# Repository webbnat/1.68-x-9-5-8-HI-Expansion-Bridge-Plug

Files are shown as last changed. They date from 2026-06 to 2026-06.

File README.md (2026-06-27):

# SHEX-BP-UHEX-54 — 1.68 × 9-5/8 High-Expansion Bridge Plug

Parametric engineering package for a retrievable, ultra-high-expansion downhole
bridge plug (1.68 in run-in OD, sets in 9-5/8 in casing) plus its setting
adapter kit and stage-1/2 internal actuators. Everything here is generated from
parametric CAD scripts: B-rep solids and STEP via `gmsh` (OpenCASCADE), 2D
manufacturing drawings via `ezdxf`, and figures/previews via `matplotlib`.

## Repository layout

```
cad/                     parametric solid models (release_solids, actuator_solids, ...)
generate_*.py            generators: full tool, actuators, setting kit
build_revisions.py       assembles the per-revision archive (Rev A / Rev B)
export/
  release/               released STEP parts + assemblies, drawings (dxf/pdf), manuals, figures
  full_tool/             complete tool: STEP + STL + previews (run-in & set)
  REVISIONS/             clean per-revision snapshots (see below)
  analysis/              engineering analysis scripts + memos (incl. DCN-12 trigger)
  drawings/              drawing generators + part specs
  _stl_archive/          large STL meshes as a multi-volume RAR (see its README)
```

## Revisions

| Revision | Folder | Complete tool (run-in / set) | Notes |
|---|---|---|---|
| **Rev B — current** | `export/REVISIONS/Rev-B_DCN-12_CURRENT/` | 47 / 48 bodies | adds the **SHEX-017** sequence/initiation sub (DCN-12 first-stroke trigger + EQ interlock) |
| Rev A — previous | `export/REVISIONS/Rev-A_DCN-01-11_PREVIOUS/` | 44 / 45 bodies | plug + setting kit + stage-1/2 bladder actuators |

Each revision folder is self-contained: engineering, design, part-specs,
drawings (dxf+pdf), STEP (parts/assemblies/full-tool), STL, and previews. See
`export/REVISIONS/README.md` for the full DCN-01…12 history.

## STL meshes

Loose `.stl` files are **git-ignored** because several exceed GitHub's 100 MB
limit. They are shipped as a multi-volume RAR under
[`export/_stl_archive/`](export/_stl_archive/README.md) and are also fully
reproducible from the scripts:

```
python generate_full_tool.py     # complete run-in / set tool STL + STEP
python build_revisions.py         # per-revision archive
```

## Environment

Python 3.11 with `gmsh`, `ezdxf`, `matplotlib`, `numpy`, `pillow`. The `.venv/`
folders are intentionally excluded; recreate with `python -m venv .venv` and
install the above.

## Documentation

- Plug design/manufacture/assembly manual — `export/release/manual/MANUAL.md`
- Setting-tool (SHEX-AK-20) manual — `export/release/manual/SETTING_TOOL_MANUAL.md`
- Stage-1/2 actuator manual (Rev B) — `export/release/manual/ACTUATOR_MANUAL.md`
- First-stroke trigger memo (DCN-12) — `export/analysis/FIRST_STROKE_TRIGGER.md`
- Release notes / DCN log — `export/release/RELEASE_NOTES.md`
- Working log / forward plan — `WORKING_LOG.md`, `FORWARD_PLAN.md`

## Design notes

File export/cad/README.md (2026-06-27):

# Full 3D CAD Package — SHEX-BP-UHEX-54

Manufacturing-oriented **B-rep STEP** solids (Gmsh OpenCASCADE kernel).  
Units: **millimetres**. Z = 0 at tool bottom (mandrel tail).

## Assembly models (`step/`)

| File | Description |
|---|---|
| `plug_set_assembly.stp` | 54" bridge plug — **SET** condition (expanded) |
| `plug_run_in_assembly.stp` | 54" bridge plug — **RUN-IN** (collapsed 1.688" OD) |
| `setting_tool_SHEX-ST-54.stp` | Setting tool — 246" (20.5 ft) module stack |

Open in **Fusion 360**, **SolidWorks**, **FreeCAD**, or **Onshape** via File → Import → STEP.

Each assembly is a **multi-body** STEP — one solid per BOM item.

## Key individual parts (`parts/`)

| File | Description |
|---|---|
| `SHEX-011_inner_mandrel.stp` | Full-length inner mandrel |
| `SHEX-001_iris_segment.stp` | Single iris segment (t=0.187 in) |
| `SHEX-001_iris_ring_16seg.stp` | Full 16-segment iris ring |
| `SHEX-008_stage1.stp` / `SHEX-009_stage2.stp` / `SHEX-010_stage3_support.stp` | Expansion stage sleeves |

## Coordinate system

- **+Z** = uphole (toward fishing neck)
- **Origin** = bottom centreline of mandrel tail

## Regenerate

```powershell
.venv\Scripts\python generate_cad.py
```

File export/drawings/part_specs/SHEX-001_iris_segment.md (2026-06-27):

# SHEX-001 — Stage 3 Iris Segment — Shop Drawing Spec

**Drawing No:** DWG-001-SHP  
**Part No:** SHEX-001  
**Qty:** **16** per plug  
**Material:** 17-4 PH H900 (H1150M)  
**Tier:** **MANUFACTURING** — **profile / EDM part** *(not a turned OD)*  
**STEP import:** `export/cad/parts/SHEX-001_iris_segment.stp` *(rough envelope — refine profile)*  
**Module ref:** `SHEX-IRIS_STACK_INDEX.md`

---

## 1. Function

One of **16** radial segments. At setting, slides on **SHEX-002** helix from collapsed nest to **deployed** arc contacting **9-5/8" 40#** casing (**8.679 in** drift).

| Parameter | Value |
|---|---|
| Angular span | **22.5°** |
| Deployed outer arc | **R 4.318 in** *(Ø8.650)* |
| Collapsed inner arc | **R 2.955 in** *(nest in module)* |
| Radial travel | **1.363 in** |

**Assembly note:** Segments are **nested in SHEX-010** at module build; module **crimped to OD 1.688** for run-in — same as stent sleeves. Shop drawing dimensions **finished segment** (deployed geometry).

---

## 2. Profile geometry (authoritative)

Arc segment in **radial plane**, extruded **axially** (plug **Z**).

| Feature | Dimension (in) | Tolerance | Notes |
|---|---|---|---|
| **Angular span** | **22.5°** | ±0.5° | |
| **Inner radius R1** | **2.955** | ±0.005 | = **5.750/2 + 0.080** |
| **Outer radius R2** | **4.318** | ±0.005 | = **8.650/2 − 0.015** |
| **Radial width** | **1.363** | — | R2 − R1 |
| **Axial length L** | **2.750** | ±0.010 | |
| **Thickness t** | **0.187** | ±0.005 | Production; **0.125** marginal @ 5000 psi FEA |

### 2.1 Arc endpoints (datum = segment bisector @ 0°)

| Point | Radius (in) | Angle from bisector |
|---|---|---|
| Inner toe | **2.955** | **±11.25°** |
| Outer toe | **4.318** | **±11.25°** |

### 2.2 Edge treatments

| Feature | Dimension (in) | Notes |
|---|---|---|
| Root fillet (inner) | **R0.030** min | |
| Outer toe chamfer | **0.025 × 45°** | Both faces |
| Side edges | Break **0.010** max | |

---

## 3. Helix follower tab

Engages **SHEX-002** groove on **inner/center side** of segment.

| Feature | Dimension (in) | Tolerance | Notes |
|---|---|---|---|
| Tab length (axial) | **0.625** | ±0.005 | |
| Tab width | **0.125** | ±0.003 | Matches helix groove |
| Tab height (radial) | **0.080** | ±0.003 | |
| Tab location | **Mid-length** on segment | — | **Z** centre of **2.750 L** |
| Tab angular position | **Bisector plane** | — | Points toward mandrel |

---

## 4. Guide toe (SHEX-010 slot)

| Feature | Dimension (in) | Notes |
|---|---|---|
| Toe radius | **R2.955** | Rides in sleeve slot §3 |
| Toe width (circ.) | **0.110** | Clearance in **0.120** slot |

---

## 5. Required drawing views (DWG-001-SHP)

| View | Scale | Content |
|---|---|---|
| A | **1:2** | **Radial end** — arc **22.5°**, R1/R2 |
| B | **1:2** | **Axial section** — **L 2.750 × t 0.187** |
| C | **3:1** | Root fillet + toe chamfer |
| D | **2:1** | Helix follower tab |
| E | **1:1** | **Plate nest layout** — **16 segments** per sheet *(optional)* |

---

## 6. Dimension checklist

- [ ] Span **22.5°**
- [ ] **R1 = 2.955**, **R2 = 4.318**
- [ ] **L = 2.750**, **t = 0.187**
- [ ] Root **R0.030** min
- [ ] Follower tab **0.625 × 0.125 × 0.080**
- [ ] Qty **16** per module on drawing
- [ ] Part number **SHEX-001**

---

## 7. General notes

```
1. UNLESS OTHERWISE SPECIFIED, DIMENSIONS ARE IN INCHES.
2. MATERIAL: 17-4 PH H900, HEAT TREAT H1150M.
3. QTY: 16 PER IRIS MODULE (ITEM 6).
4. MANUFACTURE: WIRE EDM OR CNC FROM PLATE — NOT TURNED OD.
5. FINISH: ELECTROPOLISH ALL EXPOSED FACES.
6. BREAK SHARP EDGES 0.010 MAX EXCEPT NOTED CHAMFERS.
7. ANGULARITY ±0.5° TO TAB DATUM.
8. DEPLOYED ARC RADII SHOWN — MODULE CRIMPED TO 1.688 OD AT ASSY.
9. VERIFY RADIAL TRAVEL 1.363 IN IN DWG-002-SET ASSY CHECK.
```

---

## 8. Fusion workflow

1. Design **`06_SHEX-001_iris_segment`** — one segment only.
2. Sketch arc **22.5°** between **R1/R2** → extrude **2.750**.
3. Add **follower tab** §3; fillets §2.2.
4. Drawing **DWG-001-SHP** → `shop_pdf/`.
5. In **`08_iris_run_in_assy`**: pattern **×16** @ **22.5°**, centre **Z = 20.875**.

**Reference schematic:** `dxf/DWG-001_iris_segment.dxf`

---

## 9. Inspection

| Check | Method |
|---|---|
| R1, R2 | CMM or profile gauge |
| Thickness **0.187** | Micrometer |
| Span **22.5°** | CMM / fixture |
| Tab **0.125** width | Pin gauge |

---

*Rev A — iris segment EDM profile for manufacturing.*

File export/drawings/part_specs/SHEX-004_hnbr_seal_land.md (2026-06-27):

# SHEX-004 — HNBR Seal Land Liner — Mold / Part Spec

**Drawing No:** DWG-007B-SHP  
**Part No:** SHEX-004  
**Qty:** **4** per plug (items **7–10**)  
**Material:** HNBR **90 durometer** (Shore A)  
**Tier:** **MANUFACTURING** — **molded elastomer preform** *(thin liner — not full seal OD)*  
**Module ref:** Seal lands | Schematic: `dxf/DWG-007_seal_land_module.dxf`

---

## 1. Function

Molded **thin HNBR liner** in each seal land module. **SHEX-005** petals provide anti-extrusion structure and carry the liner **outward** during setting; the liner **finishes** the seal face against casing.

| Parameter | Value |
|---|---|
| Seal lands per plug | **4** |
| Petals per land | **16** (**SHEX-005**) |
| **Set contact OD** *(in-well)* | **Ø8.720 in** |
| **Run-in module OD** *(nested)* | **Ø1.688 in** |
| Mandrel | **Ø1.550 in** |

### 1.1 Cascade nesting (Option B — authoritative)

**No single element expands from 1.688″ to 8.720″.** Total expansion is the **product of nested stages** — each module runs at **run-in OD** until its stage opens the bore for the next:

| Stage | Item | Run-in OD | Set OD | Mechanism |
|---|---|---|---|---|
| 1 | Stent + bladder | **1.688** | **3.375** | Internal bladder |
| 2 | Stent + Belleville | *(nested)* | **5.750** | Internal wedge |
| 3 | Iris + sleeve | *(nested)* | **8.650** | Helix + 16 segments |
| **4** | **Seals + petals** | *(nested)* | **8.720** | Petals deploy + liner stretch + mandrel compress |

Seal modules **ride inside** the collapsed cascade at **Ø1.688** (same body envelope as **SHEX-010**). After Stage 3 opens the bore to **~Ø8.650**, petals and HNBR **only finish the last ~0.035″ radial** to seal OD and casing drift **8.679″** — they are **not** storing a solid **Ø8.720 × 4.5″** rubber donut at run-in.

**Shop mold (this drawing):** **run-in preform** only.  
**Set OD 8.720:** **in-well energized envelope** — see **DWG-007-SET** / `build_seal_stack_assy` *(illustration)*.

---

## 2. Molded preform geometry (authoritative — DWG-007B-SHP)

Thin **carrier-wall liner** at petal zone. Datum: **Z′ = 0** at land bottom; liner centre **Z′ = 2.250**.

| Feature | Dimension (in) | Tolerance | Notes |
|---|---|---|---|
| **Radial thickness t** | **0.050** | ±0.005 | In **0.063** carrier wall |
| **Inner radius Ri** | **0.781** | +0.005 / −0.000 | At **Ø1.562** carrier bore |
| **Outer radius Ro** | **0.831** | ±0.005 | Within **Ø1.688** OD |
| **Axial length L** | **0.550** | ±0.010 | Matches **SHEX-005** active zone |
| **Angular coverage** | **360°** | — | Continuous ring per land |

*Not molded:* full **4.500** land height; **Ø8.720** set OD — those are module / performance limits.

### 2.1 Set envelope *(illustration only — not mold)*

| Feature | Value | Notes |
|---|---|---|
| Contact OD | **8.720** | After petals @ **R2 4.011** + liner stretch |
| Energize | Mandrel **+Z** | **SHEX-011** §12.6 ramps — axial compression |

### 2.2 Mold detail

| Feature | Notes |
|---|---|
| Parting line | **Mid-thickness** *(typ)* |
| Draft | **1°** min |
| Flash | **≤0.010** |
| Bond | Mechanical grip in carrier — **no bond to petal faces** |

---

## 3. Position in plug stack

| Land | Item | Plug **Z** | Module **Z′** |
|---|---|---|---|
| **1** | 7 | **26.0 – 30.5** | 0 – 4.5 |
| **2** | 8 | **30.5 – 35.0** | 0 – 4.5 |
| **3** | 9 | **35.0 – 39.5** | 0 – 4.5 |
| **4** | 10 | **39.5 – 44.0** | 0 – 4.5 |

---

## 4. Fusion workflow

| Script | Purpose |
|---|---|
| `build_SHEX_004_hnbr_seal_land` | One **preform liner** (molded part) |
| `build_SHEX_004_hnbr_mold` | Mold cavity + preform check |
| `build_seal_run_in_assy` | **4× nested lands** — 64 petals + 4 liners @ **1.688** |
| `build_seal_stack_assy` | **SET illustration** — energized envelope @ **8.720** |

---

## 5. General notes

```
1. UNLESS OTHERWISE SPECIFIED, DIMENSIONS ARE IN INCHES.
2. MATERIAL: HNBR 90 DUROMETER (SHORE A).
3. QTY: 4 PER PLUG (ITEMS 7–10).
4. MOLD THE RUN-IN PREFORM ONLY — NOT THE SET OD 8.720 CUP.
5. PETALS (SHEX-005) DEPLOY FIRST; LINER STRETCHES WITH PETAL BACKS.
6. MODULE OD AT RUN-IN = 1.688 (NESTED IN CASCADE) — NOT RADIAL CRIMP OF 8.720 RUBBER.
7. POST-MOLD TRIM FLASH; NO MOLD RELEASE IN SEAL ZONE.
```

---

*Rev B — Option B: thin preform + nested cascade; SET OD is in-well envelope.*

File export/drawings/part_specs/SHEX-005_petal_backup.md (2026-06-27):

# SHEX-005 — Seal Land Petal Backup — Shop Drawing Spec

**Drawing No:** DWG-007A-SHP  
**Part No:** SHEX-005  
**Qty:** **64** per plug (**16** per seal land × **4** lands)  
**Material:** 17-4 PH H900 (H1150M)  
**Tier:** **MANUFACTURING** — **profile / EDM part** *(not a turned OD)*  
**Module ref:** Items **7–10** (seal lands) | Schematic: `dxf/DWG-007_seal_land_module.dxf`

---

## 1. Function

Radial **anti-extrusion rib** behind **SHEX-004** HNBR cup in each seal land module. Prevents elastomer extrusion under differential pressure; reacts on **SHEX-011** seal-set ramp (§12.6).

| Parameter | Value |
|---|---|
| Per land | **16** @ **22.5°** |
| Seal lands per plug | **4** |
| Set seal land OD | **Ø8.720 in** |
| Mandrel clearance | **Ø1.550 in** |

**Assembly note:** Petals nested in seal carrier at module build. Module **OD 1.688** at run-in (**nested in cascade** — not a radial crush of deployed backup). Shop EDM profile shows **deployed backup** (same tier rule as **SHEX-001**). See **SHEX-004 Rev B** — thin HNBR liner, not full **Ø8.720** mold at run-in.

---

## 2. Profile geometry (authoritative)

Arc-sector rib in **radial plane**, extruded **axially** (plug **Z**).

| Feature | Dimension (in) | Tolerance | Notes |
|---|---|---|---|
| **Angular span** | **22.5°** | ±0.5° | **16** per land |
| **Inner radius R1** | **0.895** | ±0.005 | = **Ø1.550/2 + 0.120** |
| **Outer radius R2** | **4.011** | ±0.005 | = **Ø8.720/2 × 0.92** |
| **Radial width** | **3.116** | — | R2 − R1 |
| **Axial length L** | **0.550** | ±0.010 | Active backup length in land |
| **Plate note** | **0.55 × 1.4** | — | Legacy schematic label — radial extent governs via R1/R2 |

### 2.1 Arc endpoints (datum = petal bisector @ 0°)

| Point | Radius (in) | Angle from bisector |
|---|---|---|
| Inner toe | **0.895** | **±11.25°** |
| Outer toe | **4.011** | **±11.25°** |

### 2.2 Edge treatments

| Feature | Dimension (in) | Notes |
|---|---|---|
| Root fillet (inner) | **R0.015** min | |
| Outer toe chamfer | **0.015 × 45°** | Both faces |
| Side edges | Break **0.010** max | |

---

## 3. Position in seal land (module context)

| Feature | Value | Notes |
|---|---|---|
| Seal land axial length | **4.500** | Per land (items 7–10) |
| Petal centre **Z** *(typ)* | Mid-land | **~2.25 in** from land bottom |
| Plug **Z** land 1 bottom | **26.000** | After iris module |

*Detail mate: **SHEX-004** HNBR cup OD **8.720**; **SHEX-011** §12.6 seal ramps.*

---

## 4. Required drawing views (DWG-007A-SHP)

| View | Scale | Content |
|---|---|---|
| A | **1:2** | **Radial end** — arc **22.5°**, R1/R2 |
| B | **1:2** | **Axial section** — **L 0.550** |
| C | **3:1** | Root fillet + toe chamfer |
| D | **1:1** | **Plate nest** — 16 petals per sheet *(optional)* |

---

## 5. Dimension checklist

- [ ] Span **22.5°**
- [ ] **R1 = 0.895**, **R2 = 4.011**
- [ ] **L = 0.550**
- [ ] Root **R0.015** min
- [ ] Qty **16** per seal land on drawing
- [ ] Part number **SHEX-005**

---

## 6. General notes

```
1. UNLESS OTHERWISE SPECIFIED, DIMENSIONS ARE IN INCHES.
2. MATERIAL: 17-4 PH H900, HEAT TREAT H1150M.
3. QTY: 16 PER SEAL LAND × 4 LANDS = 64 PER PLUG.
4. MANUFACTURE: WIRE EDM OR CNC FROM PLATE — NOT TURNED OD.
5. FINISH: PASSIVATE PER SPEC; BREAK SHARP EDGES 0.010 MAX.
6. DEPLOYED BACKUP RADII SHOWN — SEAL PACK CRIMPED TO 1.688 OD AT ASSY.
7. MATES SHEX-004 HNBR (DWG-007B-SHP) — PETAL BEHIND ELASTOMER.
```

---

## 7. Fusion workflow

1. Design **`09_SHEX-005_petal_backup`** — **one petal** only.
2. Sketch **22.5°** arc sector **R1/R2** → extrude **0.550**.
3. Root fillet §2.2.
4. Drawing **DWG-007A-SHP** → `shop_pdf/`.
5. Pattern **×16 @ 22.5°** per seal land in module assy (later).

**Script:** `fusion/scripts/build_SHEX_005_petal_backup/`

---

## 8. Seal land module assy

1. **File → New Design**
2. Run **`build_seal_land_assy`** — builds **16× petals** + HNBR cup envelope for **one** land (**L 4.5**).
3. Save as **`10_seal_land_module_assy`**.
4. Repeat or pattern ×4 for full seal stack in plug GA.

**Script:** `fusion/scripts/build_seal_land_assy/`

---

## 9. Run-in / unset nest (assy viz)

Shop drawing §2 shows **deployed backup** radii. At run-in the **module OD is 1.688″** (nested in the expansion cascade). Petals **nest in the carrier bore**; outer toe may sit in **carrier wall** (same tier as iris segments in **SHEX-010** slots):

| Feature | Run-in nest (in) | Deployed backup (in) |
|---|---|---|
| Inner radius R1 | **0.778** | **0.895** |
| Outer radius R2 | **0.816** | **4.011** |
| Angular span | **22.5°** | **22.5°** |
| Axial L | **0.550** | **0.550** |

*R2 **0.816** = **Ø1.562/2 + 0.035** into carrier wall (0.063″ wall to **Ø1.688** OD).*

**HNBR (**SHEX-004**):** thin **0.050″** liner in wall — not full seal cup at run-in.

**Fusion:** `build_seal_run_in_assy` — nested **4× lands**. SET illustration: `build_seal_stack_assy`.

---

*Rev A — petal backup EDM profile for manufacturing.*

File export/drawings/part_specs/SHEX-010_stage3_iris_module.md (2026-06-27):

# Stage 3 Iris Module — Assembly & Fusion Guide

**Manufacturing index:** `SHEX-IRIS_STACK_INDEX.md` ← **start here for shop drawings**  
**Part specs:** `SHEX-010_support_sleeve.md` | `SHEX-002_helix_guide.md` | `SHEX-001_iris_segment.md`  
**Set illustration:** **DWG-002-SET** *(expanded deployed view — not for machining)*  
**Plug item:** 6  
**Plug Z range:** **18.500 – 26.000 in** (bottom → top)  
**Module length:** **7.500 in**

| Part | P/N | Qty | Shop drawing | Set viz |
|---|-----|-----|---|---|
| Support sleeve | **SHEX-010** | 1 | **DWG-012-SHP** @ **OD 1.688** | Shown expanded in **DWG-002-SET** |
| Helix guide | **SHEX-002** | 1 | **DWG-002A-SHP** | — |
| Iris segment | **SHEX-001** | 16 | **DWG-001-SHP** | Deployed in **DWG-002-SET** |
| Top retainer ring | **SHEX-002R** *(TBD)* | 1 | TBD | — |

**Drawing tiers:** See `docs/FUSION_SHOP_DRAWINGS.md` — **`-SHP`** = manufacturing (run-in); **`-SET`** = set illustration.

**Mates:** **SHEX-011** mandrel §12.5 (helix cams **Z = 19.0 – 23.0**); **SHEX-009** Stage 2 below; seal module above @ **Z = 26.0**.

---

## 1. Function

Third expansion stage: **5.750 in → 8.650 in OD** via **16 solid segments** on a **double-start helix** (lead **4.0 in**). First phase that uses setting-tool stroke (**4.0 in axial + ~2 rev rotation**).

| State | Module outer OD | Used on which drawing tier |
|---|---|---|
| **Run-in** | **1.688 in** max | **`-SHP`** manufacturing (what shop builds) |
| **Set** | **8.650 in** max | **`-SET`** illustration only (virtual deployed assy) |

---

## 2. Module envelope (plug coordinates)

**Z = 0** at plug bottom; **Z+ uphole**.

| Parameter | Value |
|---|---|
| Module bottom | **Z = 18.500** |
| Module top | **Z = 26.000** |
| Length | **7.500 in** |
| Mandrel through-bore | **Ø1.550** clearance *(mandrel §12.5 cams in this span)* |
| Set OD (deployed) | **8.650 in** |
| Collapsed substrate OD | **5.750 in** *(fixed support sleeve)* |

### 2.1 Axial zones within module *(local Z′ = 0 at module bottom)*

| Local Z′ (in) | Plug Z (in) | Zone | Content |
|---|---|---|---|
| 0.000 – 0.750 | 18.500 – 19.250 | **Bottom coupling** | Pilot / overlap with Stage 2 stent (**Ø5.750** land) |
| 0.750 – 3.250 | 19.250 – 21.750 | **Collapsed pocket** | Segments nested @ **R ≈ 2.955 – 3.100 in** |
| 3.250 – 7.250 | 21.750 – 25.750 | **Helix actuation** | **SHEX-002** guide + segment travel; **4.0 in** mandrel stroke |
| 7.250 – 7.500 | 25.750 – 26.000 | **Lock land** | Top retainer / anti-backout |

*Segment centre **Z = 20.875 in** (local **2.375 in**) — matches CAD generator.*

---

## 3. Part — SHEX-010 Support sleeve *(manufacturing: DWG-012-SHP)*

**Material:** 17-4 PH H900  
**Role:** Fixed steel shell — does **not** expand with iris.

### 3.1 Shop drawing (run-in — what machinist builds)

| Feature | Dimension (in) | Tolerance | Notes |
|---|---|---|---|
| **OD** | **1.688** | +0.000 / −0.005 | **Run-in max** — same as plug body |
| **Length** | **7.500** | ±0.010 | Full module |
| **ID** | Per mandrel + segment pocket | +0.003 / −0.000 | **Ø1.550** mandrel clearance min |
| **16 guide slots** | **22.5°** spacing | ±0.5° | All features within **1.688 OD** envelope |
| Mandrel clearance | **Ø1.560** min | — | Over **Ø1.550** mandrel |

**Do not use** `SHEX-010_stage3_support.stp` OD (**Ø5.750**) on the shop drawing — that STEP is **set-reference envelope** only.

### 3.2 Set illustration only (DWG-002-SET)

| Feature | Value | Notes |
|---|---|---|
| Substrate OD | **Ø5.750** | After Stage 2 expansion — visualization context |
| Deployed module OD | **Ø8.650** | Segments extend outside sleeve |
| STEP / `plug_set_assembly.stp` | Reference | For **`-SET`** assembly, not **`-SHP`** |

---

## 4. Part — SHEX-002 Helix guide

**Material:** Inconel 718  
**Role:** Double-start helical path; converts mandrel **axial + rotation** to segment radial motion.

| Feature | Value | Notes |
|---|---|---|
| **Form** | **Double-start helix** | 2 parallel grooves 180° apart |
| **Lead** | **4.0 in** | Axial advance per **one full rotation** |
| **Active length** | **~4.0 in** | Overlaps mandrel cam zone **Z = 19.0 – 23.0** |
| **Groove width** | **0.250** | ±0.005 — segment follower pin |
| **Groove depth** | **0.125** | ±0.003 |
| **Install position** | Local **Z′ = 3.25 – 7.25** | Fixed to **SHEX-010** or mandrel — *validate both options in skeleton* |

**Preferred architecture (Rev A):**

- **SHEX-002** = insert ring(s) fixed in **SHEX-010** bore.
- **SHEX-011** mandrel carries **helical cams** (§12.5) that drive segment followers in **SHEX-002** grooves.

**Fusion:** Model from helix path (Insert → Coil / sweep) using **lead 4.0 in**, **2 starts**, **2 rev** over **4.0 in** axial.

**Reference schematic:** `dxf/DWG-002_iris_module_assy.dxf` — VIEW 3 “LEAD 4.0 IN”.

---

## 5. Part — SHEX-001 Iris segment (×16)

**Material:** 17-4 PH H900  
**Qty:** 16 per module  
**Finish:** Electropolish; break sharp edges **0.025 in** max

| Feature | Dimension (in) | Tolerance | Notes |
|---|---|---|---|
| **Angular span** | **22.5°** | ±0.5° | 16 segments / 360° |
| **Axial length** | **2.750** | ±0.010 | — |
| **Thickness** | **0.187** | ±0.005 | Production; 0.125 marginal @ 5000 psi FEA |
| **Inner radius R1** | **2.955** | — | = 5.750/2 + **0.080** |
| **Outer radius R2** | **4.318** | — | = 8.650/2 − **0.015** |
| **Radial travel** | **1.363** | — | R2 − R1 |
| **Root fillet** | **R0.030** min | — | Toe / root |
| **Toe chamfer** | **0.25 × 45°** | — | — |
| **Helix follower slot** | **0.625 × 0.125** | — | Engages **SHEX-002** *(Detail D, DWG-001)* |

**Segment centre Z (plug):** **20.875 in**  
**Pattern:** **Circular pattern 16× @ 22.5°** about plug centreline.

**Fusion:** Import one `SHEX-001_iris_segment.stp` → refine profile → **Pattern → Circular** 16 instances.

**Reference schematic:** `dxf/DWG-001_iris_segment.dxf`

---

## 6. Deployment kinematics

| Parameter | Value |
|---|---|
| Mandrel stroke (Phase 4) | **4.0 in** + **~2 rev** |
| Radial travel per segment | **1.363 in** |
| Expansion ratio (Stage 3) | **8.650 / 5.750 = 1.50×** |
| Setting force *(typ)* | **~12 klbf** at iris *(see `docs/SETTING_SEQUENCE.md`)* |

**Run-in:** Mandrel index **0**; segments inside **Ø5.750** pocket.  
**Set end:** Mandrel **+4.0 in**; segments at **Ø8.650** OD envelope.

---

## 7. Fusion project structure

```
Plug/
├── 05_SHEX-002_helix_guide          ← DWG-002A-SHP (manufacturing)
├── 06_SHEX-001_iris_segment         ← DWG-001-SHP
├── 07_SHEX-010_support_sleeve       ← DWG-012-SHP @ OD 1.688
├── 08_stage3_iris_module_SET        ← DWG-002-SET (set illustration only)
└── 99_plug_SET                      ← DWG-003-SET plug GA
```

### 7.1 Manufacturing models (`-SHP`) first

Build and release **DWG-012-SHP**, **DWG-001-SHP**, **DWG-002A-SHP** before the set illustration.

### 7.2 Set illustration assembly (`-SET`)

| Step | Action |
|---|---|
| **1** | Create **`08_stage3_iris_module_SET`** — label drawing **NOT FOR MANUFACTURE** |
| **2** | Insert **`-SHP` part models** OR import `plug_set_assembly.stp` as reference |
| **3** | Position segments **deployed** to **Ø8.650**; use set envelopes if needed |
| **4** | Drawing **DWG-002-SET** — no run-in OD dims required; balloon to **-SHP** part numbers |
| **5** | Export PDF → `export/drawings/set_viz_pdf/` |

### 7.3 Manufacturing modeling order

| Step | Action |
|---|---|
| **1** | Model **SHEX-010** @ **OD 1.688 × 7.5 L** + **16 guide slots** → release **DWG-012-SHP** |
| **2** | Model **SHEX-001** segment profile → release **DWG-001-SHP** |
| **3** | Model **SHEX-002** helix (fits inside 1.688 bore) → release **DWG-002A-SHP** |
| **4** | Optional: run-in assy check with mandrel @ **OD ≤ 1.688** — interference only |

### 7.4 Set illustration validation (DWG-002-SET)

| Config | Mandrel ΔZ | Segment state | Check |
|---|---|---|---|
| **RUN-IN** *(reference)* | **0** | Nested in pocket | OD **≤ 1.688** |
| **DEPLOYED** | **+4.0 in** | Full radial travel | OD **8.650**; no clash with casing drift **8.679** |

Use **Fusion Configurations** in the **`-SET`** assembly only.

### 7.5 Skeleton cross-check

| Tier | Condition | Module OD | Z |
|---|---|---|---|
| **-SHP** | Run-in | **1.688** | 18.5 – 26.0 |
| **-SET** | Deployed | **8.650** | 18.5 – 26.0 |

---

## 8. Required drawing views

### DWG-012-SHP (SHEX-010 sleeve — manufacturing)

| View | Scale | Content |
|---|---|---|
| A | **1:2** | Half-section — **OD 1.688** × **7.5 L** |
| B | **1:1** | End view — slot pattern |
| C | **2:1** | Slot detail |

### DWG-002-SET (module — set illustration)

| View | Scale | Content |
|---|---|---|
| A | **1:4** broken | Module **7.5 in** — **deployed OD 8.650** |
| B | **1:4** section | Helix zone |
| C | **1:2** plan | **16 segments @ 22.5°** deployed |

---

## 9. Dimension checklist

### Manufacturing (`-SHP`)

- [ ] Module length **7.500** @ plug **Z = 18.500 – 26.000**
- [ ] Support sleeve **SHEX-010** OD **1.688** × **7.500** *(see support sleeve spec)*
- [ ] Helix guide **SHEX-002** lead **4.0 in**, double-start
- [ ] Segments **16× SHEX-001** @ **22.5°**, **t = 0.187**, **L = 2.750**
- [ ] Mandrel helix cams @ **Z = 19.0 – 23.0** *(SHEX-011 §12.5)*

### Set illustration (`-SET`) only

- [ ] Deployed OD **8.650** vs drift **8.679**
- [ ] Inner / outer segment radii **2.955 / 4.318** in deployed view

---

## 10. General notes (assembly drawing)

```
1. UNLESS OTHERWISE SPECIFIED, DIMENSIONS ARE IN INCHES.
2. STAGE 3 IRIS MODULE — ITEM 6 ON PLUG GA (DWG-003-SET).
3. THIS DRAWING TIER: see title block — SHP = MANUFACTURE / SET = ILLUSTRATION ONLY.
4. DEPLOY: SETTING TOOL AXIAL 4.0 IN + ROTATION (~2 REV) ON MANDREL.
5. MANUFACTURING PARTS: SHEX-010 @ OD 1.688 | SHEX-001 ×16 | SHEX-002.
6. SET ILLUSTRATION: DEPLOYED OD 8.650 IN — NOT A MACHINING DIMENSION.
```

---

## 11. Related files

| File | Purpose |
|---|---|
| `SHEX-011_inner_mandrel.md` §12.5 | Mandrel helix cam zone |
| `docs/SETTING_SEQUENCE.md` § Phase 4 | Setting sequence |
| `config/design_uhex_54in.yaml` → `stage3_iris` | Segment count, stroke, material |
| `cad/plug_visual.py` → `MODULES` | Stack OD/ID |
| `output/stl/stage3_iris/` | Visual STLs *(run `generate_stage3_iris.py`)* |

---

*Rev A — Stage 3 iris module assembly spec for Fusion modeling.*

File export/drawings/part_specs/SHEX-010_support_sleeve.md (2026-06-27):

# SHEX-010 — Stage 3 Iris Support Sleeve — Shop Drawing Spec

**Drawing No:** DWG-012-SHP  
**Part No:** SHEX-010  
**Qty:** 1 per plug  
**Material:** 17-4 PH H900 (H1150M)  
**Tier:** **MANUFACTURING** — **OD 1.688 in max**  
**STEP import:** `export/cad/parts/SHEX-010_stage3_support.stp` *(ignore — OD 5.750 is set-reference only)*  
**Module ref:** `SHEX-IRIS_STACK_INDEX.md`  
**Set viz:** Deployed context in **DWG-002-SET** only

---

## 1. Function

Fixed **support sleeve** for Stage 3 iris module. Does **not** expand. Provides:

- **Run-in outer envelope** **Ø1.688** (plug body OD)
- **Bore** for **Ø1.550** mandrel clearance
- **16 guide slots** for **SHEX-001** segments
- **Helix insert pocket** for **SHEX-002**

**Plug location:** **Z = 18.500 – 26.000 in** (length **7.500 in**).  
**Part coordinates:** **Z′ = 0** at **bottom face** (= plug **Z = 18.500**).

---

## 2. Authoritative dimensions (shop)

| Feature | Dimension (in) | Tolerance | Notes |
|---|---|---|---|
| **OD** | **1.688** | +0.000 / −0.005 | Run-in plug OD |
| **Length** | **7.500** | ±0.010 | |
| **ID (mandrel bore)** | **Ø1.562** | +0.003 / −0.000 | **Ø1.550** mandrel + clearance |
| **Wall (nominal)** | **0.063** | — | (1.688 − 1.562) / 2 |
| **Bottom face** | Flat | **Ra 32 µin** | Mates Stage 2 module top |
| **Top face** | Flat | **Ra 32 µin** | Lock land / seal module below |

---

## 3. Segment guide slots (16×)

Radial **internal** slots on bore for **SHEX-001** segment toes. All within **Ø1.688** OD.

| Feature | Dimension (in) | Tolerance | Notes |
|---|---|---|---|
| Count | **16** | — | |
| Angular pitch | **22.5°** | ±0.5° | Datum: slot **#1** @ **0°** |
| Slot centre **Z′** | **2.375** | ±0.010 | Aligns segment centre (plug **Z = 20.875**) |
| Slot length (axial) | **2.750** | ±0.010 | Matches segment length |
| Slot width (circ.) | **0.120** | ±0.005 | At **Ø1.562** bore |
| Slot depth (radial) | **0.055** | +0.005 / −0.000 | From bore into wall |

---

## 4. Helix guide pocket (SHEX-002)

| Feature | Dimension (in) | Notes |
|---|---|---|
| Pocket **Z′** span | **3.250 – 7.250** | **4.000 in** axial |
| Pocket ID | **Ø1.558** | **SHEX-002** insert OD + clearance |
| Pocket depth | **0.040** min | Axial groove or counterbore for insert retention |
| Retaining ring groove | **0.030 × 0.040** | At **Z′ = 7.200** *(or pin)* |

*Detail mate: `SHEX-002_helix_guide.md`.*

---

## 5. Bottom coupling (Stage 2 mate)

| Feature | Dimension (in) | Notes |
|---|---|---|
| Pilot length **Z′** | **0.000 – 0.750** | Overlap with Stage 2 stent top |
| Pilot OD | **1.688** | Same as body |
| Pilot ID | **Ø1.562** | Continuous bore |

---

## 6. Top lock land

| Feature | Dimension (in) | Notes |
|---|---|---|
| **Z′** span | **7.250 – 7.500** | **0.250 in** |
| ID step *(optional)* | **Ø1.540** | Captures segment tops / retainer |

---

## 7. Required drawing views (DWG-012-SHP)

| View | Scale | Content |
|---|---|---|
| A | **1:2** | Half-section — full **7.5 L**, bore, slots |
| B | **1:1** | End view @ **Z′ = 2.375** — **16 slots @ 22.5°** |
| C | **2:1** | Slot detail |
| D | **2:1** | Helix pocket @ **Z′ = 5.25** |
| E | **2:1** | Top lock land |

---

## 8. Dimension checklist

- [ ] OD **1.688**, length **7.500**
- [ ] Bore **Ø1.562**
- [ ] **16×** guide slots @ **22.5°**, **Z′ = 2.375**
- [ ] Helix pocket **Z′ = 3.250 – 7.250**
- [ ] Bottom / top faces flat, **Ra 32 µin**
- [ ] Part number **SHEX-010**

---

## 9. General notes

```
1. UNLESS OTHERWISE SPECIFIED, DIMENSIONS ARE IN INCHES.
2. MATERIAL: 17-4 PH H900, HEAT TREAT H1150M.
3. MANUFACTURING — RUN-IN OD 1.688 MAX. NOT Ø5.750.
4. FIXED SLEEVE — DOES NOT EXPAND WITH IRIS.
5. DEBURR SLOTS; NO BURRS IN HELIX POCKET.
6. PLUG Z: 18.500 – 26.000 IN (ITEM 6).
7. MATE SHEX-002 INSERT + 16× SHEX-001 IN MODULE ASSY.
```

---

## 10. Fusion workflow

1. Design **`07_SHEX-010_support_sleeve`** — **do not import** 5.750 STEP as finished part.
2. Revolve **Ø1.688 × 7.5 L**, bore **Ø1.562**.
3. Cut **16 slots** per §3 (sketch on plane @ **Z′ = 2.375** or wrap).
4. Cut **helix pocket** per §4.
5. Drawing **DWG-012-SHP** → `shop_pdf/`.
6. Insert into **`08_iris_run_in_assy`** with mandrel + one segment for slot fit.

---

*Rev A — manufacturing sleeve @ OD 1.688 for iris stack.*

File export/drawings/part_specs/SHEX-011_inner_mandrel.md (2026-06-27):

# SHEX-011 — Inner Mandrel — Shop Drawing Spec

**Drawing No:** DWG-011B-SHP  
**Part No:** SHEX-011  
**Qty:** 1  
**Material:** 17-4 PH H900 (H1150M)  
**STEP import:** `export/cad/parts/SHEX-011_inner_mandrel.stp` *(envelope — add top end + steps in Fusion)*  
**Mate fishing neck:** `SHEX-012_fishing_neck.md` **Rev D**  
**Related:** `SHEX-011_mandrel_tail_sleeve.md` *(tail sleeve — separate part, DWG-011A)*

---

## 1. Function

Central **setting mandrel** — drives the full plug set sequence. All modules (slips, stents, iris, seals) slide or expand on this OD.

| End | Mate |
|-----|---|
| **Top (Z = 51.0)** | **SHEX-012** fishing neck — **1½-12 UNF-2A**, **Ø1.500** shoulder + **Parker 2-216** |
| **Bottom (Z = 0)** | **SHEX-013** equalizing sub + **SHEX-011A** tail sleeve |

**Overall mandrel length: 54.0 in** (matches STEP: 3 in tail + 51 in @ **Ø1.550**). **Neck joint** at **Z = 51.0** — see **§2.2**.

**Plug assembly:** Body modules **0 – 51.0 in**; fishing neck **51.0 – 57.0 in** (6 in). **Overall plug = 57.0 in**.

---

## 2. Authoritative dimensions

Coordinate: **Z = 0 at bottom face**, **Z+ uphole**.

| Section | Z range (in) | Length (in) | OD (in) | Tolerance |
|---|---|---|---|---|
| **Tail** | 0 – 3.0 | 3.0 | **1.350** | +0.000 / −0.002 |
| **Main body** | 3.0 – 54.0 | 51.0 | **1.550** | +0.000 / −0.002 |
| **Top joint** *(machined)* | 50.0 – 51.0 | 1.0 | **1.500** | Step, thread, shoulder |
| **Overall** | 0 – 54.0 | **54.0** | — | ±0.010 |

| Feature | Value | Notes |
|---|---|---|
| Through bore | **Solid** | No through bore |
| Tail step | **Ø1.350 → Ø1.550** @ **Z = 3.0** | 30° chamfer or **R0.062** blend |
| Top step (joint) | **Ø1.550 → Ø1.500** @ **Z = 50.0** | Thread + shoulder zone |
| Shoulder face | **Z = 51.0** | **Ø1.500** + O-ring groove — mates SHEX-012 bottom |
| Module stack engagement | **Z = 0 – 51.0** | Slips, seals, iris, etc. on **Ø1.550** body |
| Straightness | **0.005 in** | Over any 12 in |
| Surface finish (slip/seal zones) | **Ra 32 µin** | Z = 3.0 – 51.0 |

### 2.1 Axial stack (this part)

```
  Z (in)    OD (in)    Section
  ───────   ────────   ─────────────────────────────
  54.0      1.550      ┌─ Top of STEP / turned bar
  51.0      1.550      │  Main body continues (no neck drift — §2.2)
  51.0      1.500      ├─ Shoulder face + O-ring groove (joint)
                        │  1½-12 UNF-2A × 1.000 (Z = 50.0 – 51.0)
  50.0      1.550 ──►  ├─ Step Ø1.550 → Ø1.500
  3.0       1.550      │  Main body — modules Z = 3 – 51
  3.0       1.350 ──►  ├─ Step Ø1.350 → Ø1.550
  0.0       1.350      └─ Tail
```

### 2.2 Fishing neck — no through-mandrel drift

**There is no requirement for the plug mandrel to pass through the fishing neck.**

| Topic | Clarification |
|---|---|
| **SHEX-012 bore (G) Ø0.750** | Wireline / internal clearance in the **neck only** — **not** a mandrel through-bore |
| **How neck attaches** | **Separate part** — **1½-12 UNF-2B** picks up male thread at **Z = 50 – 51**; bottom face seals on **Ø1.500** shoulder @ **Z = 51** |
| **Engagement depth** | **~1.0 in** thread + shoulder — within neck **bottom 1.5 in zone** only |
| **Z = 51 – 54 on mandrel** | **Ø1.550** bar stock to **Z = 54** per STEP; **does not enter** neck bore (G). In assembly, **SHEX-012 occupies Z = 51 – 57 externally** — it is **not** a tube the mandrel slides through |
| **Z = 51 – 54 on mandrel (lathe)** | Top **3 in** of the **54 in** bar above the joint plane — **plain Ø1.550** unless parted off. **Not functionally required** inside the neck; may be **trimmed at Z = 51** after threading or left as non-interfering stub per neck OD envelope |

**Assembly model (side view):**

```
  Z=57  ──  SHEX-012 pin / AMT (neck only)
  Z=51  ──  ├─ Neck bottom face ═══ Shoulder @ mandrel Z=51
            │   (thread engagement 50–51 only)
            │   NO mandrel drift through neck bore (G)
  Z=51  ──  Upper slip top / module stack end
  Z=0   ──  Mandrel tail
```

---

## 3. Mandrel top end — mates SHEX-012 Rev D

```
  Plug Z     SHEX-012 (female)                 SHEX-011 (male)
  ───────    ─────────────────────             ─────────────────
  57.0       1" AMT / pin Ø1.375
  51.0       bottom seal face ─────────────►  shoulder @ Z=51.0
             counterbore Ø1.530 × 0.500          O-ring groove
             1½-12 UNF-2B × 1.000                  1½-12 UNF-2A × 1.000
  51.5       pin Ø0.125 (assembly) ◄──────────► pin @ Z=51.500
  46.5       (upper slip bore Ø1.550 clr)
```

### 3.1 Shoulder and O-ring groove (male)

| Feature | Dimension (in) | Tolerance | Notes |
|---|---|---|---|
| Shoulder face | **Z = 51.0** | — | Joint face — mates SHEX-012 bottom |
| Shoulder OD | **Ø1.500** | +0.000 / −0.002 | — |
| Shoulder flatness | — | **0.001 FIM** | Groove + seal land |
| Shoulder finish | **Ra 32 µin** | max | — |
| **O-ring** | **Parker 2-216** | — | Viton 90; AS568-216 |
| Groove OD | **Ø1.181** | ±0.003 | In shoulder face |
| Groove ID | **Ø1.087** | ±0.003 | — |
| Groove width **G** | **0.094** | ±0.003 | — |
| Groove depth **H** | **0.086** | +0.002 / −0.000 | — |
| Groove corner | **R0.015** | min | — |

### 3.2 Male thread and pin

| Feature | Spec | Notes |
|---|---|---|
| Thread | **1½-12 UNF-2A** | (= 1.500-12 UNF) |
| Thread length | **1.000 in** | **Z = 50.000 – 51.000** |
| Thread major OD | **Ø1.500** | — |
| Thread run-out | **0.030 × 45°** | At **Z = 50.000** |
| Cross pin | **Ø0.125 in**, **1 place** | Drill after neck makeup |
| Pin centre **Z** | **51.500** | Plug assembly coordinates |
| Makeup torque | **250 ft-lb** min | O-ring is primary seal |

**1½-12 UNF-2A reference (ANSI B1.1):**

| Diameter | Size (in) |
|---|---|
| Major (external) | **1.5000** |
| Pitch diameter (2A) | **1.4565 – 1.4622** |
| Minor (external, ref) | **1.4224** |

### 3.3 Mates SHEX-012 female (cross-check)

| Female (SHEX-012) | Male (this part) |
|---|---|
| Counterbore **Ø1.530 × 0.500** | Shoulder **Ø1.500** + groove clears in counterbore |
| **1½-12 UNF-2B × 1.000** | **1½-12 UNF-2A × 1.000** |
| Bottom seal face | Shoulder face @ **Z = 51.0** |
| Pin @ **Z = 51.500** | Pin @ **Z = 51.500** |

---

## 4. Mandrel bottom end — mates SHEX-013 / tail sleeve

| Feature | Spec | Notes |
|---|---|---|
| Bottom face | Flat, **Ra 63 µin** | **Z = 0** |
| Bottom OD | **Ø1.350 × 3.000** | Inside tail sleeve |
| Step to main | **Z = 3.0** | **Ø1.350 → Ø1.550** |
| Equalizing sleeve | Slides on **Ø1.550** | Above **Z = 3.0** |

*(Tail sleeve **SHEX-011A** — separate drawing DWG-011A-SHP.)*

---

## 5. Module boundary map (for drawing sections)

Use for **broken views**, **section cuts**, and Fusion **assembly** ballooning.

| Item | Module | Z start | Z end | Mandrel OD @ zone |
|---|---|---|---|---|
| 1 | Mandrel tail / sleeve | 0 | 3.0 | 1.350 |
| 2 | Bottom equalizing sub | 3.0 | 5.0 | 1.550 (through bore clearance) |
| 3 | Lower slips | 5.0 | 9.5 | 1.550 + taper (§12.3) |
| 4 | Stage 1 stent + bladder | 9.5 | 13.5 | 1.550 |
| 5 | Stage 2 stent + Belleville | 13.5 | 18.5 | 1.550 |
| 6 | Stage 3 iris | 18.5 | 26.0 | 1.550 + helix cams (§12.5) |
| 7–10 | Seal lands 1–4 | 26.0 | 44.0 | 1.550 + ramps (§12.6) |
| 11 | Upper MTM | 44.0 | 46.5 | 1.558 load land (§12.7) |
| 12 | Upper slips | 46.5 | 51.0 | 1.550 + taper (§12.8) |
| 13 | Fishing neck *(SHEX-012)* | 51.0 | 57.0 | — *(threads onto mandrel @ Z=51; no mandrel drift)* |

*Detailed OD features per zone — **§12**.*

---

## 6. Features to model in Fusion (not in STEP)

| Priority | Feature | Location | Status |
|---|---|---|---|
| **1** | Top step **Ø1.550 → Ø1.500** | Z = 50.0 | Required — §3 |
| **1** | **1½-12 UNF-2A × 1.000** | Z = 50.0 – 51.0 | Required — §3 |
| **1** | Shoulder + **O-ring groove** | Z = 51.0 | Required — §3 |
| **1** | Pin drill **Ø0.125** | Z = 51.500 | Assembly |
| **2** | Tail step **Ø1.350 → Ø1.550** | Z = 3.0 | Required — §4 |
| **2** | Lower slip **expander cone** | Z = 6.25 – 7.75 | §12.3 |
| **2** | Iris **drive helix / cams** | Z = 19.0 – 23.0 | §12.5 |
| **2** | Seal-set **ramps ×4** | Z = 26.0 – 44.0 | §12.6 |
| **2** | Upper slip **expander cone** | Z = 48.25 – 49.75 | §12.8 |
| **3** | MTM **load land** | Z = 44.75 – 45.25 | §12.7 |

---

## 12. Mandrel functional zones — OD steps and setting features

Provisional **Rev D.3** geometry derived from module stack (§5), setting sequence (`docs/SETTING_SEQUENCE.md`), and stroke budget (iris **4.0 in**, seals **~5.5 in**, slips **~1.5 in**). **Validate in Fusion skeleton assembly** before locking shop dims on SHEX-002 / SHEX-004 / SHEX-006 drawings.

### 12.1 Design basis

| Item | Value |
|---|---|
| Mandrel OD (main) | **Ø1.550** +0.000 / −0.002 |
| Module bore on mandrel | **Ø1.550 +0.003 / −0.000** (slip / seal carriers) |
| Setting motion | Mandrel translates **+Z (uphole)** **~11.0 in** total vs fixed outer stack during Phases 4–6 |
| Run-in index | Mandrel **bottom face @ Z = 0**; top joint plane @ **Z = 51.0** |
| Finish | **Ra 32 µin** on all zones in §12.3 – §12.8 |

**Motion convention (Phases 4–6):** Tool push at fishing neck advances mandrel **uphole (+Z)** through fixed module carriers. Iris helix zone is engaged first, then seal ramps, then slip expander cones.

**Elevation (functional OD — not to scale):**

```
  Z=51  ──  Ø1.500 thread / shoulder (§3)
  Z=50  ──  ├─ step Ø1.550 → Ø1.500
  Z=49.8──  │  upper slip taper Ø1.550 → Ø1.620
  Z=45.3──  │  MTM load Ø1.558
  Z=42  ──  │  seal ramp 4 ↑
  Z=37.5──  │  seal ramp 3 ↑
  Z=33  ──  │  seal ramp 2 ↑
  Z=28.5──  │  seal ramp 1 ↑
  Z=23  ──  │  iris helix cams (2-start, L=4.0)
  Z=19  ──  │
  Z=18.5──  │  smooth Ø1.550 (stages 1–2)
  Z=9.5 ──  │
  Z=7.8 ──  │  lower slip taper Ø1.550 → Ø1.620
  Z=6.3 ──  │
  Z=3   ──  ├─ step Ø1.350 → Ø1.550
  Z=0   ──  └─ tail Ø1.350
```

### 12.2 Zone summary

| Zone | Item | Z range (in) | Mandrel OD / feature | Setting stroke |
|---|---|---|---|---|
| A | Tail | 0 – 3.0 | **Ø1.350** step @ 3.0 | — |
| B | Equalizing / tail sleeve | 3.0 – 5.0 | **Ø1.550** smooth | — |
| C | Lower slips | 5.0 – 9.5 | **Expander cone** §12.3 | ~0.75 in (of 1.5 in slip budget) |
| D | Stage 1 stent | 9.5 – 13.5 | **Ø1.550** smooth | Internal (no tool stroke) |
| E | Stage 2 stent | 13.5 – 18.5 | **Ø1.550** smooth | Internal (no tool stroke) |
| F | Stage 3 iris | 18.5 – 26.0 | **Helix cams** §12.5 | **4.0 in** + rotation |
| G | Seal lands 1–4 | 26.0 – 44.0 | **Compression ramps ×4** §12.6 | **~5.5 in** total |
| H | Upper MTM | 44.0 – 46.5 | **Load land** §12.7 | Included in seal push |
| I | Upper slips | 46.5 – 51.0 | **Expander cone** §12.8 | ~0.75 in (of 1.5 in slip budget) |
| J | Top joint | 50.0 – 51.0 | **Ø1.500** thread + shoulder | — |

### 12.3 Lower slip expander cone (Item 3 — SHEX-007)

Wedges (8×) ride on mandrel OD; axial advance forces teeth outward against casing.

| Feature | Dimension (in) | Tolerance | Notes |
|---|---|---|---|
| Smooth lead-in | **Z = 5.000 – 6.250** | — | **Ø1.550** — slip carrier bore clearance |
| Taper start | **Z = 6.250** | — | **Ø1.550** |
| Taper end | **Z = 7.750** | — | **Ø1.620** |
| Taper length | **1.500** | — | **12° included** (6° half-angle) |
| Smooth trail | **Z = 7.750 – 9.500** | — | **Ø1.620** × 1.750 then blend to **Ø1.550** @ **Z = 9.500** *(0.125 × 45° chamfer)* |
| Radial rise | **0.070** | — | Drives wedge ~0.35 in radial at OD 8.72 |

**Run-in:** Taper centred in slip module; wedges retracted on **Ø1.550** land.  
**Set:** Mandrel **+Z ~0.75 in** positions full taper under wedges (Phase 6, shared with upper slip).

### 12.4 Stage 1 & 2 — smooth bearing lands (Items 4–5)

| Feature | Dimension (in) | Notes |
|---|---|---|
| OD | **Ø1.550** | No mandrel OD steps — stents expand in annulus |
| Z span | **9.500 – 18.500** | Stage 1 + Stage 2 modules |
| Scribe lines *(optional)* | **Z = 13.500** | Assembly reference only — 0.010 deep max |

### 12.5 Stage 3 iris drive zone (Item 6 — mates SHEX-002 / SHEX-001)

**SHEX-002** (Inconel 718) carries the **double-start helix path** (lead **4.0 in**). Mandrel carries **drive cams** that transfer tool rotation + axial push to iris segments via the fixed helix guide.

| Feature | Dimension (in) | Tolerance | Notes |
|---|---|---|---|
| Smooth bearing | **Z = 18.500 – 19.000** | — | **Ø1.550** — iris module entry |
| **Helix cam zone** | **Z = 19.000 – 23.000** | — | **4.0 in** active stroke span |
| Cam form | **2-start**, lead **L = 4.0** | — | Double-start — **2.0 in axial per 360°** |
| Cam rise | **0.062** above **Ø1.550** | ±0.003 | Radial drive for segment followers |
| Cam width *(axial)* | **0.250** | ±0.005 | At peak OD |
| Cam peak OD | **Ø1.674** | — | = 1.550 + 2×0.062 |
| Root between cams | **Ø1.550** | — | Bearing surface for guide sleeve |
| Smooth exit | **Z = 23.000 – 26.000** | — | **Ø1.550** — lock / support land |
| Rotation | **2 rev** max | — | Over 4.0 in stroke (matches SHEX-002) |

**Run-in:** Cams at **Z = 19.0 – 23.0** aligned with collapsed iris pocket (segments @ ID 5.750).  
**Set end:** Mandrel advanced **+4.0 in**; segments deployed to OD **8.650**.

*Cross-check:* `export/drawings/dxf/DWG-002_iris_module_assy.dxf` — **LEAD 4.0 IN**, **16 seg @ 22.5°**.

### 12.6 Seal-set compression ramps (Items 7–10 — SHEX-004 / SHEX-005)

Each **4.5 in** seal module has a **1.375 in** effective compression ramp on mandrel OD. Continued **+Z** advance after iris forces HNBR cups radially against casing; metal petals react on ramp shoulder.

| Land | Module Z | Ramp Z (start → end) | Start OD | End OD | Ramp angle |
|---|---|---|---|---|---|
| **1** | 26.0 – 30.5 | **27.125 → 28.500** | **Ø1.550** | **Ø1.582** | **3° included** |
| **2** | 30.5 – 35.0 | **31.625 → 33.000** | **Ø1.550** | **Ø1.582** | **3° included** |
| **3** | 35.0 – 39.5 | **36.125 → 37.500** | **Ø1.550** | **Ø1.582** | **3° included** |
| **4** | 39.5 – 44.0 | **40.625 → 42.000** | **Ø1.550** | **Ø1.582** | **3° included** |

Between ramps: **Ø1.550** clearance bands (**~2.625 in** between ramp ends).

| Feature | Dimension (in) | Notes |
|---|---|---|
| Radial rise per ramp | **0.032** | (1.582 − 1.550) / 2 |
| Ramp length | **1.375** | ×4 ≈ **5.5 in** tool stroke |
| Downhole ramp face | **30° chamfer** | Transition to **Ø1.550** land |
| Uphole ramp face | **Flat** | Compresses petal carrier / HNBR back face |

**Run-in:** All ramps upstream (downhole side) of seal carriers — cups relaxed on **Ø1.550**.  
**Set:** Sequential ramp engagement lands 1 → 4 as mandrel advances **+Z** after iris.

### 12.7 Upper MTM load land (Item 11 — SHEX-003)

| Feature | Dimension (in) | Notes |
|---|---|---|
| Smooth approach | **Z = 44.000 – 44.750** | **Ø1.550** |
| **Load land** | **Z = 44.750 – 45.250** | **Ø1.558** × **0.500** — axially compresses 3-ring MTM stack |
| Smooth exit | **Z = 45.250 – 46.500** | **Ø1.550** |
| Radial rise | **0.008** | Metal-to-metal preload only — no elastomer |

### 12.8 Upper slip expander cone (Item 12 — SHEX-006)

Mirror of §12.3 — same geometry, upper module.

| Feature | Dimension (in) | Notes |
|---|---|---|
| Smooth lead-in | **Z = 46.500 – 48.250** | **Ø1.550** |
| Taper start | **Z = 48.250** | **Ø1.550** |
| Taper end | **Z = 49.750** | **Ø1.620** |
| Taper length | **1.500** | **12° included** |
| Blend to joint zone | **Z = 49.750 – 50.000** | **Ø1.620 → Ø1.550** before top step @ **Z = 50.0** |

**Set:** Final **~0.75 in** mandrel travel (Phase 6) positions taper under upper wedges.

### 12.9 Setting stroke index — mandrel vs stack

Mandrel **bottom face fixed @ Z = 0**; values are **cumulative +Z travel** from run-in index at start of Phase 4.

| Phase | Function | Cumulative +Z (in) | Mandrel feature engaged |
|---|---|---|---|
| — | Run-in / Phases 1–3 | **0.0** | Internal stents only |
| 4 | Stage 3 iris | **0.0 → 4.0** | §12.5 helix cams + **2 rev** |
| 5 | Seal compression | **4.0 → 9.5** | §12.6 ramps 1 → 4 |
| 6 | Slip set | **9.5 → 11.0** | §12.3 lower + §12.8 upper cones |
| 7 | MTM load-up | *(within Phase 5 push)* | §12.7 load land |
| 8 | Tool release | **11.0 + 0.5** overtravel | Release collet — not on mandrel |

**Tool stroke budget:** 4.0 + 5.5 + 1.5 + 0.5 = **11.5 in required** / **12.0 in available** (0.5 in margin).

### 12.10 OD step ledger — machining order (tail → head)

Use for lathe programming and Fusion timeline. All dims from **Z = 0** bottom face.

| Step | Z from | Z to | OD (in) | Feature |
|---|---|---|---|---|
| 1 | 0.000 | 3.000 | **1.350** | Tail |
| 2 | 3.000 | 5.000 | **1.550** | Step + equalizing zone |
| 3 | 5.000 | 6.250 | **1.550** | Lower slip lead-in |
| 4 | 6.250 | 7.750 | **1.550 → 1.620** | Lower slip taper |
| 5 | 7.750 | 9.500 | **1.620 → 1.550** | Lower slip trail blend |
| 6 | 9.500 | 18.500 | **1.550** | Stage 1 & 2 smooth |
| 7 | 18.500 | 19.000 | **1.550** | Iris entry |
| 8 | 19.000 | 23.000 | **1.550 + helix cams** | Iris drive (§12.5) |
| 9 | 23.000 | 26.000 | **1.550** | Iris exit |
| 10 | 26.000 | 27.125 | **1.550** | Seal 1 lead-in |
| 11 | 27.125 | 28.500 | **1.550 → 1.582** | Seal 1 ramp |
| 12 | 28.500 | 31.625 | **1.550** | Seal 1–2 gap |
| 13 | 31.625 | 33.000 | **1.550 → 1.582** | Seal 2 ramp |
| 14 | 33.000 | 36.125 | **1.550** | Seal 2–3 gap |
| 15 | 36.125 | 37.500 | **1.550 → 1.582** | Seal 3 ramp |
| 16 | 37.500 | 40.625 | **1.550** | Seal 3–4 gap |
| 17 | 40.625 | 42.000 | **1.550 → 1.582** | Seal 4 ramp |
| 18 | 42.000 | 44.750 | **1.550** | Seal 4 exit / MTM approach |
| 19 | 44.750 | 45.250 | **1.558** | MTM load land |
| 20 | 45.250 | 48.250 | **1.550** | MTM exit / upper slip lead-in |
| 21 | 48.250 | 49.750 | **1.550 → 1.620** | Upper slip taper |
| 22 | 49.750 | 50.000 | **1.620 → 1.550** | Blend to top step |
| 23 | 50.000 | 51.000 | **1.500** | Thread + shoulder (§3) |
| 24 | 51.000 | 54.000 | **1.550** | Top stub (§2.2 — optional trim) |

### 12.11 Fusion validation checklist

Before releasing DWG-011B-SHP:

- [ ] Skeleton assembly — module envelope cylinders @ §5 Z ranges; no interference at run-in and full-set positions
- [ ] Iris — **4.0 in** stroke + **2 rev** clears SHEX-010 bore and deploys segments to **Ø8.650**
- [ ] Seals — each ramp **1.375 in** travel compresses HNBR to casing ID **8.679** drift with petals engaged
- [ ] Slips — both tapers develop wedge load within **1.5 in** combined stroke
- [ ] MTM — **0.500 in** land preloads rings without elastomer contact
- [ ] Top joint — thread + shoulder still @ **Z = 51.0** after all steps modeled

---

## 7. Required drawing views

| View | Type | Scale | Content |
|---|---|---|---|
| A | Front elevation | **1:12 broken** | Full **54.0** length — OD step ledger §12.10 |
| B | Section B-B @ top | **2:1** | Thread, shoulder, groove |
| C | Section C-C @ Z=3 | **2:1** | Tail step |
| D | Section D-D @ Z=26 | **2:1** | Seal ramp 1 (§12.6) |
| E | Section E-E @ Z=21 | **2:1** | Iris helix cams (§12.5) |
| F | Section F-F @ Z=7 | **2:1** | Lower slip taper (§12.3) |
| G | Section G-G @ Z=49 | **2:1** | Upper slip taper (§12.8) |
| DETAIL H | O-ring groove | **4:1** | Parker 2-216 dims |
| DETAIL I | Thread | **4:1** | 1½-12 UNF-2A × 1.000 |
| DETAIL J | Pin | **4:1** | Ø0.125 @ Z=51.500 |
| DETAIL K | Top step @ joint | **2:1** | Ø1.550 → Ø1.500 @ Z=50 |

---

## 8. Dimension checklist

- [ ] Overall length **54.000**
- [ ] Tail **Ø1.350 × 3.000**
- [ ] Main body **Ø1.550** (Z = 3 – 54, with steps per §12.10)
- [ ] Top joint **Ø1.500** thread + shoulder (Z = 50 – 51)
- [ ] Tail step @ **Z = 3.000**
- [ ] Top step @ **Z = 50.000**
- [ ] Lower slip taper **Ø1.550 → Ø1.620** @ **Z = 6.250 – 7.750** (§12.3)
- [ ] Iris helix cams **2-start, L = 4.0** @ **Z = 19.000 – 23.000** (§12.5)
- [ ] Seal ramps **×4**, **Ø1.550 → Ø1.582 × 1.375** (§12.6)
- [ ] MTM load land **Ø1.558 × 0.500** @ **Z = 44.750 – 45.250** (§12.7)
- [ ] Upper slip taper **Ø1.550 → Ø1.620** @ **Z = 48.250 – 49.750** (§12.8)
- [ ] Shoulder face @ **Z = 51.000**, flatness **0.001 FIM**
- [ ] O-ring groove OD **1.181**, ID **1.087**, G **0.094**, H **0.086**
- [ ] Thread **1½-12 UNF-2A × 1.000**
- [ ] Pin **Ø0.125** @ **Z = 51.500** (assembly note)
- [ ] Straightness **0.005 / 12 in**
- [ ] Ra **32 µin** on Z = 3 – 51
- [ ] Material **17-4 PH H1150M**
- [ ] Part number **SHEX-011**

---

## 9. General notes (copy to drawing)

```
1. UNLESS OTHERWISE SPECIFIED, DIMENSIONS ARE IN INCHES.
2. MATERIAL: 17-4 PH H900, HEAT TREAT H1150M.
3. Ø1.550 BODY: 32 µin Ra ON SLIP/SEAL TRAVEL ZONES (Z=3 TO 51).
4. TOP END: 1½-12 UNF-2A × 1.000 — MATE SHEX-012 Rev D @ Z=51.0.
5. SHOULDER Ø1.500 @ Z=51.0; PARKER 2-216 VITON IN GROOVE BEFORE NECK MAKEUP.
6. TORQUE 250 FT-LB MIN AT NECK MAKEUP; DRILL Ø0.125 PIN @ Z=51.500 AFTER.
7. MANDREL 54.0 IN PER STEP; JOINT @ Z=51.0; NO DRIFT THROUGH SHEX-012 BORE (G) — §2.2.
8. FUNCTIONAL OD STEPS: §12 — SLIP TAPER, IRIS CAMS, SEAL RAMPS, MTM LAND.
9. NO DIRECT FASTENER TO SLIP CARTRIDGES — MANDREL-CENTRIC STACK.
10. CHROME PLATE NOT REQUIRED (CONTRAST ST-010 STROKE MANDREL).
11. DEBURR; INSPECT STRAIGHTNESS BEFORE ASSEMBLY.
```

---

## 10. Inspection

| Check | Method |
|---|---|
| OD 1.550 / 1.350 | Micrometer, 3 places per 12 in |
| OD 1.500 top stub | Micrometer |
| Thread | 1½-12 UNF ring gauge |
| O-ring groove | Groove dims §3.1 |
| Shoulder flatness | Surface plate + indicator |
| Straightness | V-block + dial indicator |
| Length 54.000 | Large caliper / CMM |
| Slip tapers (§12.3, §12.8) | Profile gauge / CMM @ Z = 7 & 49 |
| Seal ramps (§12.6) | Micrometer @ peak OD **1.582** |
| Iris cams (§12.5) | CMM or helix template |

---

## 11. Fusion workflow (quick start)

1. New design **`04_SHEX-011_inner_mandrel`**.
2. Import `SHEX-011_inner_mandrel.stp` — **54.0 in / Ø1.550** envelope matches §2.
3. Model **top joint** @ Z = 51 (step, thread, groove) — §3.
4. Model **tail step** @ Z = 3 (§4).
5. Add **functional OD steps** per **§12.10** ledger (slip tapers → iris cams → seal ramps → MTM land).
6. Resolve **Z = 51 – 54** per §2.2 (optional trim at shoulder — not a neck drift requirement).
7. Create drawing with **broken view** (§7) — section at each feature zone.
8. Assembly-check in skeleton with module envelopes (§12.11) and **SHEX-012** at joint @ Z = 51.

---

*Rev D.3 — §12 mandrel functional zones: slip tapers, iris helix cams, seal ramps, MTM land, OD step ledger.*

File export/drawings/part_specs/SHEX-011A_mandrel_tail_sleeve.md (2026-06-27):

# SHEX-011A — Mandrel Tail Sleeve — Shop Drawing Spec

**Drawing No:** DWG-011A-SHP  
**Part No:** SHEX-011A *(same as mandrel tail sleeve in BOM)*  
**Qty:** 1  
**Material:** 4140 HT (AMS 6415), 28–32 HRC  
**STEP import:** `export/cad/parts/SHEX-011_mandrel_tail_sleeve.stp`  
**Mate mandrel:** `SHEX-011_inner_mandrel.md` §4

---

## 1. Function

Machined **tail sleeve** over mandrel **Ø1.350** bottom section. Provides wear surface and bottom guide through **SHEX-013** equalizing sub.

---

## 2. Dimensions

| Feature | Value | Tolerance |
|---|---|---|
| Overall length | **3.000 in** | ±0.010 |
| OD | **1.350 in** | ±0.005 |
| ID (mandrel clearance) | **Ø1.352 +0.002/−0.000** | Slip fit on mandrel tail |
| Bottom chamfer | **0.040 × 45°** | — |
| Top chamfer | **0.030 × 45°** | — |

Coordinate: **Z = 0 – 3.0** on plug (same as mandrel tail).

---

## 3. Drawing views

| View | Scale | Content |
|---|---|---|
| Front section | 1:1 | OD, ID, length |
| Detail A | 2:1 | Chamfers |

---

## 4. Notes

```
1. MATERIAL: 4140 HT, 28-32 HRC.
2. SLIP FIT OVER SHEX-011 MANDREL Ø1.350 TAIL (Z=0 TO 3).
3. BOTTOM FACE FLUSH WITH MANDREL BOTTOM FACE @ Z=0.
```

---

*Rev A — companion to SHEX-011 inner mandrel.*

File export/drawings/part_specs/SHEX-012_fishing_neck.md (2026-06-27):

# SHEX-012 — Fishing Neck / Top Sub — Shop Drawing Spec

**Drawing No:** DWG-010-SHP  
**Part No:** SHEX-012  
**Qty:** 1  
**Material:** 4140 HT (AMS 6415), 28–32 HRC  
**STEP import:** `export/cad/parts/SHEX-012_fishing_neck.stp` *(envelope only — remake in Fusion per this spec)*  
**Schematic ref:** `export/drawings/dxf/DWG-010_fishing_neck.dxf` *(layout reference — superseded by Rev D dims)*  
**Mate mandrel:** `SHEX-011_inner_mandrel.md` §3 **Rev D**

---

## 1. Function

Top connector on the plug. **1 in AMT** top connection (pin section + external thread) mates with setting-tool crossover. **Bottom** threads onto **SHEX-011** mandrel (**1½-12 UNF**) with **Parker 2-216** face seal. Locates on upper slip ring at **Z = 51.0 in** (no direct fastener to slips). See **§5**.

**Plug length note:** This neck is **6.000 in** (was 3.000 in) — **overall plug assembly = 57.0 in** unless another module is shortened.

---

## 2. Authoritative dimensions

Coordinate: **Z = 0 at bottom face** (mandrel end), **Z+ uphole**.

| Feature | Value | Tolerance | Notes |
|---|---|---|---|
| **Overall length** | **6.000 in** | ±0.010 | — |
| **Main body OD** | **1.688 in** | ±0.005 | Middle section |
| **Main body length** | **3.000 in** | — | Z = 1.500 – 4.500 (derived: 6 − 1.5 − 1.5) |
| **Pin section (A) OD** | **1.375 in** | ±0.005 | Top section |
| **Pin section (A) length** | **1.500 in** | ±0.005 | Z = 4.500 – 6.000 |
| **Through bore (G)** | **Ø0.750 in** | +0.002 / −0.000 | Full length where bored |
| **Top chamfer** | **0.030 × 45°** | — | AMT / external thread lead |
| **External thread (top)** | **1 3/8-8 UN-2A × 1.125 in** | Class 2A | On pin section; major Ø1.375 |
| **Top connection** | **1 in AMT** | — | Per API 11BR / shop AMT gauge |
| **Bottom chamfer** | **0.040 × 45°** | — | Bore / counterbore entry |
| **Seal counterbore** | **Ø1.530 in × 0.500 in deep** | +0.005 / −0.000 | From bottom face |
| **Internal thread (bottom)** | **1½-12 UNF-2B × 1.000 in** | Class 2B | (= 1.500-12 UNF) |
| **Total bottom zone** | **1.500 in** | — | Z = 0 – 1.500 (counterbore + thread + seal face) |
| **Bottom seal face** | Flat | 0.001 FIM | Ra 32 µin max; compresses O-ring |
| **Anti-rotation pin** | **Ø0.125 in**, 1 place | — | Assembly drill @ **Z = 51.500** plug assy |

### 2.1 Axial stack (this part)

```
  Z (in)    Section
  ───────   ─────────────────────────────────────
  6.000     ┌─ Top — 1" AMT / 1 3/8-8 UN-2A (1.125 L)
  4.500     ├─ Pin section (A)  Ø1.375 × 1.500
            │     Through bore Ø0.750
  4.500     ├─ Main body  Ø1.688 × 3.000
  1.500     │
  1.500     ├─ Bottom zone  (total 1.500)
            │     Counterbore Ø1.530 × 0.500
            │     1½-12 UNF-2B × 1.000
  0.000     └─ Bottom seal face → mandrel Ø1.500 shoulder
```

---

## 3. Features to model in Fusion

| Item | Spec | Notes |
|---|---|---|
| Top connection | **1 in AMT** | Mate to setting-tool crossover |
| External thread | **1 3/8-8 UN-2A × 1.125** | On **Ø1.375** pin section |
| Top chamfer | **0.030 × 45°** | Thread lead |
| Through bore **(G)** | **Ø0.750** | Through main body + pin section |
| Main body | **Ø1.688 × 3.000** | — |
| Pin section **(A)** | **Ø1.375 × 1.500** | — |
| Seal counterbore | **Ø1.530 × 0.500** | From bottom face |
| Internal thread | **1½-12 UNF-2B × 1.000** | Within bottom zone |
| Bottom seal face | **Ra 32 µin**, **0.001 flatness** | Parker **2-216** compression |
| Bottom chamfer | **0.040 × 45°** | Bore entry |
| Pin hole | **Ø0.125**, 1 place | After mandrel makeup |

---

## 4. Inspection

| Check | Method |
|---|---|
| Overall length | 6.000 ±0.010 |
| Main body OD | 1.688 ±0.005 |
| Pin section OD | 1.375 ±0.005 |
| Through bore **(G)** | Ø0.750 plug gauge |
| External thread | **1 3/8-8 UN-2A** ring gauge |
| 1 in AMT | Go/no-go AMT gauge |
| Internal thread | **1½-12 UNF-2B** plug gauge |
| Counterbore | Ø1.530 × 0.500 depth |
| Seal face | Flatness 0.001 FIM; Ra 32 µin |
| Hardness | 28–32 HRC spot check |

---

## 5. Mates and assembly

### 5.1 Part directly below — upper slip cartridge (SHEX-006)

| | Fishing neck | Upper slip module |
|--|---|---|
| Position | Item **13** — top of plug | Item **12** — directly below |
| Axial (57 in plug) | **Z = 51.0 – 57.0 in** | **Z = 46.5 – 51.0 in** |
| Run-in OD | **1.688 in** (main body) / **1.375 in** (pin) | **1.688 in** |
| Set OD | **1.375 in** (pin only) | **8.720 in** |

**No direct fastener to slip cartridge.** Bottom seal face @ **Z = 51.0** locates on mandrel shoulder; slip ring top face is adjacent at same plane.

```
        Section at Z ≈ 51 in

              ┌─── SHEX-012  Ø1.688 body / Ø1.375 pin (above)
              │      Through bore Ø0.750
    ──────────┼──●──────────  SHEX-011 mandrel Ø1.550
              │  │
    ══════════╪══╪══════════  SHEX-006 upper slip (Ø1.688 run-in)
              └──┘
```

---

### 5.2 Primary connection — inner mandrel (SHEX-011)

**Threaded + O-ring face seal + pin.** Mandrel groove per **`SHEX-011_inner_mandrel.md` §3** — **update male thread length to 1.000 in**.

| Feature | Fishing neck (female) | Mandrel (male) |
|---|---|---|
| Thread | **1½-12 UNF-2B × 1.000** | **1½-12 UNF-2A × 1.000** |
| Seal counterbore | **Ø1.530 × 0.500** | — |
| Shoulder / seal | Bottom face on **Ø1.500** shoulder | **Ø1.500** shoulder @ **Z = 51.0** |
| O-ring | **Parker 2-216** Viton — compressed by bottom face | Groove in shoulder face |
| Pin | **Ø0.125**, 1 place | @ **Z = 51.500** |
| Makeup torque | **250 ft-lb** min | — |

#### Female internal dimensions (bottom zone — 1.500 in total)

Machine from **bottom face (Z = 0)** upward:

| Zone | ID (in) | Depth | Tolerance | Notes |
|---|---|---|---|---|
| **Seal counterbore** | **Ø1.530** | **0.500** | +0.005 / −0.000 | Clears O-ring; non-threaded |
| **Tap / thread** | **1½-12 UNF-2B** | **1.000** | Class 2B | Overlaps counterbore zone |
| **Through bore (G)** | **Ø0.750** | Above bottom zone | +0.002 / −0.000 | Full length |

**1½-12 UNF-2B reference (ANSI B1.1):**

| Diameter | Size (in) |
|---|---|
| Major (internal) | **1.5000** |
| Pitch diameter (2B) | **1.4508 – 1.4565** |
| Minor (internal, ref) | **1.4224** |

#### **1 3/8-8 UN-2A reference (external, pin section)**

| Diameter | Size (in) |
|---|---|
| Major (external) | **1.3750** |
| Pitch diameter (2A, ref) | **1.3210 – 1.3270** |
| Thread length | **1.125** |
| Pitch | **8 UN** (0.125 in) |

#### Assembly sequence

1. Stack plug modules on mandrel.
2. Install **Parker 2-216** in mandrel shoulder groove.
3. Thread neck onto mandrel (**1.000 in** engagement min); bottom face seats on **Ø1.500** shoulder.
4. Torque **250 ft-lb**.
5. Drill **Ø0.125** pin @ **Z = 51.500**.
6. Make up setting tool **1 in AMT** at surface (§5.3).

---

### 5.3 Top connection — setting tool (SHEX-ST-54)

| Feature | Spec |
|---|---|
| Connection | **1 in AMT** |
| Pin section | **Ø1.375 × 1.500** |
| External thread | **1 3/8-8 UN-2A × 1.125** — mates tool crossover **internal thread** |
| Through bore **(G)** | **Ø0.750** — wireline / mandrel clearance |
| Makeup | At **surface** before run-in |

---

## 6. Required drawing views

| View | Type | Scale | Content |
|---|---|---|---|
| A | Front half-section | 1:2 | Full 6.000 length, bore **(G)** |
| B | Right end (top) | 1:1 | Pin **Ø1.375**, AMT |
| DETAIL C | External thread | 2:1 | **1 3/8-8 UN-2A × 1.125** |
| DETAIL D | Bottom zone | 2:1 | Counterbore **Ø1.530 × 0.500**, **1½-12 UNF-2B × 1.000** |
| DETAIL E | Slip interface | 2:1 | Bottom face @ Z = 51.0 |
| DETAIL F | Pin hole | 4:1 | Ø0.125 @ Z = 51.500 |
| DETAIL G | Seal face + O-ring | 2:1 | Parker **2-216** |

---

## 7. Dimension checklist

- [ ] Overall length **6.000**
- [ ] Main body **Ø1.688 × 3.000**
- [ ] Pin section **(A) Ø1.375 × 1.500**
- [ ] Through bore **(G) Ø0.750**
- [ ] External thread **1 3/8-8 UN-2A × 1.125**
- [ ] Top connection **1 in AMT**
- [ ] Top chamfer **0.030 × 45°**
- [ ] Counterbore **Ø1.530 × 0.500**
- [ ] Internal thread **1½-12 UNF-2B × 1.000**
- [ ] Total bottom zone **1.500**
- [ ] Bottom chamfer **0.040 × 45°**
- [ ] Bottom seal face flatness **0.001 FIM**, Ra 32 µin
- [ ] O-ring **Parker 2-216** (on mandrel)
- [ ] Pin **Ø0.125** @ Z = 51.500
- [ ] Part number **SHEX-012**

---

## 8. General notes (copy to drawing)

```
1. UNLESS OTHERWISE SPECIFIED, DIMENSIONS ARE IN INCHES.
2. TOLERANCES: ±0.005 IN; BORES ±0.001 IN; ANGLES ±0.5°.
3. MATERIAL: 4140 HT PER AMS 6415, 28-32 HRC.
4. BREAK ALL SHARP EDGES 0.010 R UNLESS NOTED.
5. TOP CONNECTION: 1 IN AMT; EXTERNAL THREAD 1 3/8-8 UN-2A × 1.125.
6. THROUGH BORE (G): Ø0.750.
7. BOTTOM THREAD: 1½-12 UNF-2B × 1.000 — MATE SHEX-011 Ø1.500 SHOULDER.
8. COUNTERBORE Ø1.530 × 0.500 FROM BOTTOM FACE.
9. SEAL: PARKER 2-216 VITON IN MANDREL GROOVE; COMPRESS WITH BOTTOM FACE.
10. TORQUE 250 FT-LB MIN; DRILL Ø0.125 PIN @ Z=51.500 AFTER MAKEUP.
11. NO DIRECT FASTENER TO SHEX-006 SLIP CARTRIDGE.
12. PLUG ASSY LENGTH WITH THIS NECK: 57.0 IN (WAS 54.0 IN).
13. DEBURR AND INSPECT 100% BEFORE ASSEMBLY.
```

---

*Rev D — 6.000 in length; 1 in AMT top; 1 3/8-8 UN-2A; 1½-12 UNF bottom; Ø1.530 × 0.500 counterbore.*

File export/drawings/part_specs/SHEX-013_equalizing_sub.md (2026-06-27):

# SHEX-013 — Bottom Equalizing Sub — Shop Drawing Spec

**Drawing No:** DWG-013-SHP  
**Part No:** SHEX-013  
**Qty:** 1  
**Material:** 4140 HT (AMS 6415), 28–32 HRC  
**Tier:** **MANUFACTURING** (`-SHP`) — **OD ≤ 1.688 in**  
**STEP import:** `export/cad/parts/SHEX-013_bottom_equalizing_sub.stp` *(envelope only — wrong ID bore; rebuild per §2)*  
**Mechanism ref:** `docs/SETTING_SEQUENCE.md` §6 Phase 1  
**Mates:** **SHEX-011** mandrel **Ø1.550** @ plug **Z = 3 – 5**; **SHEX-011A** tail sleeve below

---

## 1. Function

Bottom sub on plug (**plug item 2**, **Z = 3.000 – 5.000 in**). During **run-in**, radial ports **open** to equalize pressure above/below plug. Before setting, **sliding sleeve** shifts to **close ports** (Stage 1 pilot — no tool stroke). On **retrieval**, ports reopen.

**Part coordinates:** **Z = 0** at **bottom face** of this part (downhole end = plug **Z = 3.0**).

---

## 2. Authoritative dimensions (manufacturing)

| Feature | Dimension (in) | Tolerance | Notes |
|---|---|---|---|
| **Overall length** | **2.000** | ±0.005 | |
| **OD** | **1.688** | +0.000 / −0.005 | Run-in plug OD |
| **ID (mandrel bore)** | **Ø1.562** | +0.003 / −0.000 | Clearance on **Ø1.550** mandrel |
| **Wall thickness** | **0.063** | — | (1.688 − 1.562) / 2 — thin annulus |
| **Bottom face** | Flat | **Ra 32 µin** | Seats at plug **Z = 3.0** |
| **Top face** | Flat | **Ra 32 µin** | Butts lower slip / mandrel stack |

**Do not use STEP ID Ø0.750** — that envelope is obsolete. Mandrel is **Ø1.550** through this zone.

### 2.1 Axial stack (this part)

```
  Z′ (in)   Section
  ───────   ─────────────────────────────
  2.000     ┌─ Top face (plug Z = 5.0)
  1.625     │  Sleeve travel zone (closed @ top)
  1.250     │  Port centre plane (Z′ = 1.000)
  0.375     │  Sleeve travel (open @ bottom)
  0.000     └─ Bottom face (plug Z = 3.0)
```

---

## 3. Features to model in Fusion

### 3.1 Equalizing ports (run-in OPEN)

Thin-wall annulus — ports sized for **0.063 in** radial wall.

| Item | Spec | Notes |
|---|---|---|
| Port count | **4×** radial, **90°** apart | |
| Port form | **Ø0.062** **or** slot **0.050 × 0.125** | Through wall to **Ø1.562** bore |
| Port centre **Z′** | **1.000** | From bottom face |
| Angular position | **0 / 90 / 180 / 270°** | Datum = pin hole or scribe |

### 3.2 Sliding sleeve (thin annulus ring)

| Item | Dimension (in) | Tolerance | Notes |
|---|---|---|---|
| **OD** | **1.680** | +0.000 / −0.002 | Slides in body bore **Ø1.688** ID region |
| **ID** | **1.554** | +0.003 / −0.000 | Clears **Ø1.550** mandrel |
| **Length** | **1.200** | ±0.005 | |
| **Sleeve ports** | **4×** match §3.1 | Align with body ports when **OPEN** |
| **Closed position** | Sleeve shifts **+0.375** toward top (**Z′**) | Ports **misaligned** |
| **Open position** | Sleeve bottom @ **Z′ = 0.100** | Ports aligned |
| Pilot bore *(optional)* | **Ø0.250** × **0.300** deep | Top of sleeve — Stage 1 pilot *(TBD)* |

### 3.3 Static seals (body ↔ mandrel)

| Groove | Location **Z′** | O-ring | Notes |
|---|---|---|---|
| Lower | **0.250** | **Parker 2-212** Viton | Housing groove in **Ø1.562** bore |
| Upper | **1.750** | **Parker 2-212** Viton | — |

**Parker 2-212 groove (housing in ~1.562 bore / 1.550 shaft):**

| Feature | Dimension (in) | Tolerance |
|---|---|---|
| Groove diameter | **1.575** | ±0.003 |
| Groove width **G** | **0.103** | ±0.003 |
| Groove depth **H** | **0.070** | +0.002 / −0.000 |

### 3.4 Anti-rotation

| Item | Spec |
|---|---|
| Pin | **Ø0.093 × 0.250** deep, **1 place** |
| Pin location | Body OD, **Z′ = 0.500**, drive sleeve slot |

---

## 4. Required drawing views (DWG-013-SHP)

| View | Type | Scale | Content |
|---|---|---|---|
| A | Front half-section | **2:1** | Full length — ports, sleeve, grooves |
| B | Section **B-B** @ **Z′ = 1.000** | **2:1** | Port pattern — **OPEN** solid / **CLOSED** dashed |
| C | Right end | **1:1** | OD **1.688**, bore **1.562** |
| DETAIL D | O-ring groove | **4:1** | §3.3 |
| DETAIL E | Sleeve travel | **2:1** | **0.375** shift, open vs closed |
| DETAIL F | Port | **4:1** | Ø0.062 or slot dims |

---

## 5. Dimension checklist

- [ ] Overall length **2.000**
- [ ] OD **1.688**
- [ ] Bore **Ø1.562** (mandrel **Ø1.550** clearance)
- [ ] Ports **4×** @ **Z′ = 1.000**, **90°** spacing
- [ ] Sleeve **OD 1.680 × ID 1.554 × L 1.200**
- [ ] Sleeve travel **0.375** (open → closed)
- [ ] O-ring grooves **2×** @ **Z′ = 0.250 / 1.750**
- [ ] Anti-rotation pin **Ø0.093**
- [ ] Surface finish **Ra 32 µin** on bore and faces
- [ ] Part number **SHEX-013**

---

## 6. General notes (copy to drawing)

```
1. UNLESS OTHERWISE SPECIFIED, DIMENSIONS ARE IN INCHES.
2. MATERIAL: 4140 HT, AMS 6415, HEAT TREAT 28-32 HRC.
3. MANUFACTURING DRAWING — RUN-IN OD 1.688 MAX.
4. PRESSURE-CONTAINING — 100% PT ALL PORTS AFTER MACHINING.
5. SLEEVE MUST TRAVEL 0.375 IN MIN WITHOUT BINDING.
6. ASSEMBLE WITH VITON 2-212 IN GROOVES; SILICONE GREASE.
7. FUNCTIONAL TEST: FLOW OPEN (ALIGNED); BLOCKED CLOSED (MISALIGNED).
8. PLUG Z LOCATION: 3.000 – 5.000 IN (ITEM 2).
9. SEE SETTING_SEQUENCE §6 PHASE 1 FOR OPEN/CLOSE TIMING.
```

---

## 7. Assembly context

| Neighbour | Plug Z | Interface |
|---|---|---|
| Below | **3.0** bottom face | Open annulus / wellbore |
| Above | **5.0** top face | Lower slip module / mandrel **Ø1.550** |
| Mandrel | Through bore | **Ø1.550** — sleeve slides on mandrel OD |
| **SHEX-011A** tail sleeve | **0 – 3.0** | Below this sub on mandrel tail |

---

## 8. Fusion workflow

1. New design **`02_SHEX-013_equalizing_sub`**.
2. **Do not** trust STEP bore — model from §2: **Ø1.688 × 2.0 L**, bore **Ø1.562**.
3. Model **4× ports** @ **Z′ = 1.0** (§3.1).
4. Model **sleeve** as separate body (§3.2) — use **Component** for drawing section views.
5. Cut **O-ring grooves** @ **Z′ = 0.25 / 1.75** (§3.3).
6. **Drawing → From Design** → **DWG-013-SHP**; dimension per §5.
7. Export PDF → `export/drawings/shop_pdf/DWG-013-SHP.pdf`.
8. Mate-check with **SHEX-011** mandrel @ plug **Z = 3 – 5**.

---

## 9. Inspection

| Check | Method |
|---|---|
| OD / length | Micrometer / caliper |
| Bore **Ø1.562** | Bore gauge |
| Port location | CMM or pin gauge @ **Z′ = 1.0** |
| Sleeve travel | Mandrel + sleeve functional test |
| Pressure test | 100% PT per note 4 |

---

*Rev B — manufacturing dims for Ø1.550 mandrel / 1.688 OD annulus; STEP Ø0.750 obsolete.*

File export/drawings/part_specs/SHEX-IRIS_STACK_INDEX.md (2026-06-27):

# Stage 3 Iris Stack — Manufacturing Focus

**Plug item 6** | **Z = 18.500 – 26.000 in** | **Module length 7.500 in**

**Deferred:** SHEX-013 equalizing sub — pick up after iris stack is released.

---

## Manufacturing drawings (`-SHP`) — build in this order

| Order | Part | Drawing | Spec sheet | Fusion design |
|---|---|---|---|---|
| **1** | Support sleeve | **DWG-012-SHP** | `SHEX-010_support_sleeve.md` | `build_SHEX_010_support_sleeve` |
| **1a** | Stage 1 stent | **DWG-009-SHP** | *(generate_drawings)* | `build_SHEX_008_stage1_stent` |
| **1b** | Stage 2 stent | **DWG-011-SHP** | *(generate_drawings)* | `build_SHEX_009_stage2_stent` |
| **2** | Helix guide | **DWG-002A-SHP** | `SHEX-002_helix_guide.md` | `build_SHEX_002_helix_guide` |
| **3** | Iris segment ×16 | **DWG-001-SHP** | `SHEX-001_iris_segment.md` | `06_SHEX-001_iris_segment` |
| **4** | Run-in assy check | — | `SHEX-010_stage3_iris_module.md` §7 | `build_iris_run_in_assy_rev1` |
| **4b** | Cascade run-in (S1–S3) | — | cascade Rev1 | `build_expansion_cascade_run_in_assy_rev1` |
| **5** | Set illustration | **DWG-002-SET** | Module spec §7.2 | `build_iris_set_assy_rev1` |
| **5b** | Cascade SET (S1–S3) | — | cascade Rev1 | `build_expansion_cascade_set_assy_rev1` |

**Set viz only (after `-SHP` parts):** `DWG-002-SET`, `DWG-003-SET`.

---

## Run-in rule (manufacturing)

| Part | Max cylindrical OD on shop drawing |
|---|---|
| **SHEX-010** sleeve | **1.688 in** |
| **SHEX-002** helix insert | **≤ 1.560 in** OD (fits in sleeve bore) |
| **SHEX-001** segment | **Profile part** — not a turned OD; EDM/laser from plate |

**SHEX-001** is dimensioned in **deployed arc geometry** (radii to **Ø8.650**). Sixteen segments are **nested in the sleeve at assembly**, then the module is **crimped to 1.688 OD** for run-in — same concept as stent sleeves.

---

## Stack section (run-in — manufacturing)

```
        ┌──────────────────────────────  OD 1.688  ── SHEX-010
        │  ┌─ 16× SHEX-001 segments (nested in annulus)
        │  │  ┌─ SHEX-002 helix grooves (fixed in sleeve bore)
        │  │  │  ║  SHEX-011 mandrel Ø1.550 + helix cams §12.5
        │  │  │  ║
        └─────────┴──┴──────────────────
              ← 7.500 in →
```

---

## Mandrel interface (SHEX-011 — complete)

| Mandrel feature | Plug Z | Mates |
|---|---|---|
| Helix cams (2-start, L=4.0) | **19.0 – 23.0** | **SHEX-002** + segment followers |
| Smooth bearing | 18.5 – 19.0, 23.0 – 26.0 | Sleeve bore |

---

## Key numbers (all tiers)

| Parameter | Run-in (`-SHP`) | Set (`-SET` viz only) |
|---|---|---|
| Module OD | **1.688** | **8.650** |
| Mandrel | **Ø1.550** | **Ø1.550** |
| Iris stroke | — | **4.0 in** + **~2 rev** |
| Segments | **16 @ 22.5°** | Deployed to casing |

---

## Related files

| File | Purpose |
|---|---|
| `SHEX-010_support_sleeve.md` | Sleeve shop drawing spec |
| `SHEX-002_helix_guide.md` | Helix insert shop drawing spec |
| `SHEX-001_iris_segment.md` | Segment EDM shop drawing spec |
| `SHEX-010_stage3_iris_module.md` | Module + set viz guide |
| `SHEX-011_inner_mandrel.md` §12.5 | Mandrel helix cams |
| `config/design_uhex_54in.yaml` | `stage3_iris` block |

---

*Use this index as the manufacturing entry point for the iris stack.*

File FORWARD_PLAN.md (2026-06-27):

# SHEX-BP-UHEX-54 — Forward Plan

Living to-do / decision queue. Companion: [`WORKING_LOG.md`](WORKING_LOG.md).
Status keys: [ ] open, [~] in progress, [x] done, [!] blocked/decision needed.

---

## Active: setting-tool package (session 2)

- [x] Review repo setting-tool state; verify existing SHEX-AK-20 outputs.
- [x] Web-verify market tool stroke/force/OD (E-4 #05/#10/#20, Model J, B-series, HST).
- [x] Reconcile two-actuator "two-stroke" architecture vs 10/11.5 in stroke story.
- [x] Setting-tool manual (`SETTING_TOOL_MANUAL.md`): design+assumptions,
      market comparison, manufacturing, rig-up/operations.
- [x] Manual figures (string GA, interface section rigged/released, two-stroke,
      market conflict, stroke budget).
- [x] Verify SHEX-AK-20 STEP + ST-DWG drawings; render previews.
- [x] Update RELEASE_NOTES to include the kit + setting-tool manual.
- [x] Final verification pass; update WORKING_LOG.

## Active: stage 1/2 internal actuators (session 3) — COMPLETE

- [x] Establish annulus budget (0.146 in radial) and expansion targets.
- [x] Engineering analysis (`actuator_design.py`): pressures, forces, sizing.
- [x] Decide mechanism: DCN-10 ductile stent; DCN-11 stage-2 = 2nd bladder,
      Belleville = hold-only; energy = well pressure (CT / hydrostatic).
- [x] CAD (`cad/actuator_solids.py`) + STEP/STL parts & run-in/deployed
      assemblies (`generate_actuators.py`); round-trip verified.
- [x] Drawings ACT-DWG-014A/014B/014C/015/016 (DXF+PDF).
- [x] Figures + `ACTUATOR_MANUAL.md` (SHEX-MAN-003); RELEASE_NOTES updated.

## Open engineering items (carried, not resolved here)

- [!] **Actuator FEA + full-scale test.** Mesh plastic expansion (pressure,
      strain, fatigue, post-expansion recoil stiffness) per stage; bladder +
      stent deploy test in a representative annulus. First-order hand calcs only.
- [ ] **Burst-disk / orifice selection.** Crack pressures p1<p2 vs the well
      hydrostatic window per conveyance/depth; metering-orifice delay across temp.
- [ ] **Ratchet retrieval kinematics.** How the deployed stents re-collapse and
      the body-lock rings release on pull-out (inherited open item).
- [ ] **Mandrel update.** Add the charge-port drillings + ratchet bands to the
      SHEX-011 mandrel drawing/model (currently referenced, not cut on the part).
- [ ] **DCN-10 propagation.** Update SHEX-008/009 shop sheets to the ductile
      expandable alloy.
- [!] **Thru-tubing force conflict.** 45 klbf needs a ~3.8 in (#20) tool that
      cannot pass small tubing. Decision needed: (a) accept casing/large-bore
      deployment for the #20 kit (current assumption), or (b) re-architect
      seals+slips as pressure-energized so a ≤1.9 in / ≤10 klbf thru-tubing
      tool can set it. Affects whether "thru-tubing" is literal.
- [!] **Setting-force FEA.** 45 klbf release stud is an estimate; the real
      iris+seal+slip resistance is unverified (plug open item, MANUAL §1.10).
- [ ] **ST-DCN-3 thread verification.** Crosslink-sleeve and setting-mandrel
      thread callouts (3.250-8 UN, 1.500-12 UNF) are assumed; confirm against
      the specific tool make/serial before cutting the kit.
- [x] **First-stroke trigger / EQ interlock (DCN-12)** — designed AND built into
      a new revision. Memo `export/analysis/FIRST_STROKE_TRIGGER.md` (SHEX-EM-001)
      + `trigger_design.py`; commanded initiation (CT applied dP + ball seat /
      e-line EFI gate) + completion-gated sequencing + EQ pilot closes first;
      fail-safe states defined.
      - [x] CAD **SHEX-017** sub + **017A** arming sleeve + **017B** reference
            piston; wired into `add_actuator_hardware` (full tool Rev B 47/48).
      - [x] Drawing **ACT-DWG-017** (DXF+PDF, 3 views).
      - [x] `ACTUATOR_MANUAL.md` **Rev B** (§1.4–1.6, §4, DCN-12) + RELEASE_NOTES.
      - [x] `fig_act_trigger` schematic + DCN-12 sequence figure.
      - [!] **Still test/FEA-dependent (cannot close on paper):** EFI/gas-gen
            qualification; arming-sleeve + shear-pin calibration vs temperature;
            full-scale completion-gating deploy test; ball-seat / Model-J
            pressure interface; **SHEX-013 arming-port + SHEX-011 manifold
            drillings** to be cut on the actual mandrel/sleeve drawings.
- [ ] **Owen / Schlumberger interface variants.** Repeat-precision / Owen #20
      clones share the Baker interface; a Schlumberger-specific adapter would
      need that tool's bottom-sub drawing.

## Superseded / parked

- [x] (parked) Bespoke electromechanical SHEX-ST-54 — reference only; not a
      practical deliverable. Files kept under `First Pass Files/` and
      `export/analysis/setting_tool_design.py`.

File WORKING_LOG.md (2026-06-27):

# SHEX-BP-UHEX-54 — Working Log

Reverse-chronological engineering log. Newest entry on top. Each entry:
date, who, what changed, why, and what to check next. Companion file:
[`FORWARD_PLAN.md`](FORWARD_PLAN.md).

---

## 2026-06-13 — Revision archive (clear Rev A vs Rev B separation)

**Author:** Fable (AI), session 3 (cont.).

**Why:** user could not tell old-revision vs new-revision parts apart and asked
for each revision's full deliverable set in one folder, with the complete
run-in & set tool STL in the latest folder.

**What changed:**

- Added `build_revisions.py` and an `INCLUDE_SEQ_SUB` toggle in
  `cad/actuator_solids.py` (skips the DCN-12 sub to reconstruct pre-DCN-12).
- Built `export/REVISIONS/` with two **self-contained** snapshots, each holding
  engineering / design / part-specs / drawings(dxf+pdf) / step(parts,
  assemblies, full-tool) / stl(full-tool + sub-assemblies) / previews:
  - **`Rev-B_DCN-12_CURRENT/`** — latest. Complete tool **47 / 48 bodies**;
    includes SHEX-017/017A/017B, ACT-DWG-017, trigger memo, ACTUATOR_MANUAL
    Rev B. Full-tool STL copied from current build (run-in 28.5 MB, set 140 MB).
  - **`Rev-A_DCN-01-11_PREVIOUS/`** — regenerated with the trigger sub OFF:
    complete tool **44 / 45 bodies** (run-in 27.6 MB, set 139 MB), no SHEX-017 /
    ACT-DWG-017 / trigger files; carries a Rev-A scope note in place of the
    Rev B actuator manual.
- `export/REVISIONS/README.md` indexes both revisions + the full DCN history.
- Canonical working copies under `export/release/`, `export/full_tool/`,
  `export/analysis/` are unchanged; the archive is the clean per-revision view.

**Check next:** revisions are file snapshots; regenerate via `build_revisions.py`
if parts change. Open engineering items unchanged (FORWARD_PLAN).

---

## 2026-06-13 — DCN-12 built into a new revision (SHEX-017 + full-tool Rev B)

**Author:** Fable (AI), session 3 (cont.).

**Why:** user approved building the DCN-12 trigger/interlock architecture and
asked for it in a new revision.

**What changed:**

- `cad/actuator_solids.py`: new builders **SHEX-017** sequence/initiation sub
  (gate + EFI/pilot port + manifold + metering orifice + ref-piston seal lands),
  **SHEX-017A** stage1->2 arming sleeve (shear-pinned shuttle), **SHEX-017B**
  reference/ball-seat piston. Wired into `add_actuator_hardware` (rides the
  mandrel group), so they appear in every assembly incl. the full tool.
- `generate_actuators.py`: 3 new parts exported (round-trip OK, 1 solid each);
  sub-assemblies now 23 bodies (was 20).
- `export/drawings/generate_actuator_drawings.py`: **ACT-DWG-017** (3 views:
  housing / arming sleeve / reference piston) DXF+PDF; QA-rendered, labels and
  title-block clearances fixed.
- `figures_actuators.py`: updated `fig_act_sequence` to the DCN-12 story; added
  **`fig_act_trigger`** (why passive fails | commanded+completion-gated chain).
- `ACTUATOR_MANUAL.md` -> **Rev B**: new §1.4-1.6 (energy / trigger DCN-12 /
  sequence), §4.2-4.4 (CT ball+dP / e-line EFI ops + fail-safe state table),
  Part-3 SHEX-017 rows, **DCN-12** in Part 5, refreshed open items + file index.
- `RELEASE_NOTES.md`: DCN-12 entry + SHEX-017 / memo / full-tool Rev B index.
- `generate_full_tool.py`: manifest tagged **revision B**; regenerated
  `export/full_tool/` -> RUN-IN **47 bodies**, SET **48 bodies** (+3), STL +
  previews refreshed.

**Verification:** all 10 actuator parts export as single solids; full tool both
states build clean (47/48); previews confirm slim run-in and staged set.

**Status:** DCN-12 design BUILT (CAD/drawings/manual/figures/full-tool Rev B).
Remaining items are test/FEA-dependent (EFI/gas-gen qual, shear-pin calibration,
completion-gating deploy test, ball-seat/Model-J interface) — carried in
FORWARD_PLAN.

---

## 2026-06-13 — First-stroke TRIGGER + EQ interlock worked properly (DCN-12 proposed)

**Author:** Fable (AI), session 3 (cont.).

**Why:** the top open item — the trigger / equalizing-sleeve interlock that
makes the "first stroke" *real* — was only ever a narrative (burst disk
p1<p2 + 30 s orifice + "pilot cracks first"). Pressure-tested it; it does not
hold up.

**Key finding (proven, not asserted):** a passive burst disk referenced to a
sealed/atmospheric chamber sees **absolute hydrostatic**, which rises while
running in, so it **fires on the way down, not at depth**. There is no single
absolute-pressure setting that survives run-in to a deep target *and* fires
only at target depth (`trigger_design.py` §1). Order also isn't enforced
(p1/p2 a few hundred ft apart) and stage-2's 1898 cc can't come from any
annulus-fit chamber — it must come from the well. So passive pressure
triggering is **fatally** position-blind.

**Proposed fix (DCN-12):** separate the three jobs the old concept conflated —
- **Energy/volume** = the well (CT pump fluid, or wellbore hydrostatic), *gated*.
- **Initiation** = a position-correct **command**: CT applied differential
  (+~1500 psi over annulus, depth-independent) + ball seat; or e-line **EFI
  gate** that opens and lets hydrostatic fill (mirrors the E-4).
- **Sequencing** = **completion-gated**: each stent's bottom-out pressure
  climb shifts a shear-pinned arming sleeve (~1720 psi) that uncovers the next
  stage's feed port. The EQ pilot (SHEX-016A) strokes first → closes SHEX-013 →
  uncovers stage-1 port, so EQ-close-before-S1 is mechanically guaranteed.
Defines fail-safe states (collapsed / EQ-only / S1-only / S1+2 / set) and a
shift-to-release retrieval path. Adds new sub **SHEX-017** (gate + ball seat +
reference piston + arming sleeve + manifold); re-tasks SHEX-013/014C/015E/016A.

**Work done:** `export/analysis/trigger_design.py` (+ `.json`) — proves §1,
sizes the CT margin, e-line hydrostatic window, completion-shift pressure,
pilot force, stage-2 fill time (~tens of s), fail-safe table, full sequence.
`export/analysis/FIRST_STROKE_TRIGGER.md` (SHEX-EM-001) — the engineering memo.

**Status:** architecture defined + grounded; **DCN-12 proposed, not yet built**
into CAD/drawings/manual (offered as next step, awaiting go-ahead). FORWARD_PLAN
item moved to in-progress with the build plan.

---

## 2026-06-13 — Complete full-tool rebuild (plug + actuators), new folder

**Author:** Fable (AI), session 3 (cont.).

**Why:** the existing full-tool assemblies (`export/release/.../SHEX-BP-UHEX-54_
RUN-IN/_SET`) predated the stage 1/2 actuators and did not contain them. User
asked for fresh run-in and set tools built from all current parts, in a new
folder.

**What changed:**

- `cad/actuator_solids.py`: factored the hardware registration into
  `add_actuator_hardware(m, bladder_state, dz)` so it can be injected into any
  assembly with the correct mandrel-group shift.
- `cad/release_solids.py` `build_assembly()`: now injects the SHEX-014/015/016
  actuator hardware (mandrel-mounted → rides the mandrel group; bladders shown
  folded/spent in both end states, the inflated transient stays in
  `SHEX-ACT-S12_DEPLOYED`). Stent material updated to ductile per DCN-10.
- `generate_full_tool.py`: new generator → **`export/full_tool/`**.

**New deliverable (`export/full_tool/`):**

- `step/SHEX-BP-UHEX-54_FULL_RUN-IN.stp` (44 bodies) and `..._FULL_SET.stp`
  (45 bodies incl. casing ref) — the single complete tool model.
- `stl/` meshes + `png/` iso & section previews (run-in uses radial-exaggerated
  view; set uses true proportions, casing hidden).
- `manifest_full_tool.json` (body lists per state).

**Verification:** both STEP build clean (44 / 45 bodies); previews confirm the
slim Ø1.688 run-in and the staged set geometry (slips, stage 1/2, iris, 4 seal
lands, MTM, mandrel pin extended +10).

**Note:** `build_assembly` is now canonical for the complete tool, so re-running
`generate_release.py` would also pick up the actuators. The pre-existing
`export/release/.../SHEX-BP-UHEX-54_{RUN-IN,SET}` files were left untouched.

---

## 2026-06-13 — Stage 1/2 internal actuators (session 3, IN PROGRESS)

**Author:** Fable (AI), session 3.

**Goal:** design the internal stage-1/2 actuators that the two-actuator
architecture depends on (the "first stroke"). Until now these were referenced
(`SHEX-014` bladder, `SHEX-015` Belleville) but never engineered or modelled.
Carried as the top open item in FORWARD_PLAN.

**Geometry budget established (from `cad/release_solids.py`):**

- Stage-1 zone Z 9.5–13.5 (4.0 in); Stage-2 zone Z 13.5–18.5 (5.0 in).
- Mandrel is necked to **Ø1.270** (the DCN-1 helix neck, Z 10.4–25.9) through
  both zones → annulus radius 0.635.
- Stent sleeves (SHEX-008/009): ID 1.562 (r 0.781), OD 1.688, wall 0.063.
- **Available annulus = 0.781 − 0.635 = 0.146 in radial** (0.292 diametral) —
  this is the entire space the actuators must live in. Tight.
- Expansion targets: stage 1 OD 1.688→3.375 (ΔR 0.844/side); stage 2
  3.375→5.750 (ΔR 1.188/side). Neither contacts the 8.679 casing drift.

**Key early finding (drives the mechanism choice):** a self-contained stored-
energy spring/Belleville big enough to expand a stent (~10 klbf-class radial)
cannot fit a 0.146-in annulus. Therefore the actuators are **pressure-driven**
(wellbore hydrostatic / applied CT pressure admitted through a burst disk),
with the Belleville stack repurposed as the **hold-open / preload** element
rather than the prime mover. Documented as DCN-11 (see analysis).

**Mechanism decisions (corrections to the inherited concept):**

- **DCN-10** — stents SHEX-008/009 re-specified 17-4 PH H900 → ductile
  expandable alloy (annealed 316L / Ni): a balloon-expandable mesh must
  plastically hinge ~2x; H900 cracks.
- **DCN-11** — stage 2 prime mover changed from Belleville/swage wedge → a
  **second inflatable bladder**. A rigid expander starting ≤ stent ID 1.562
  cannot grow to back the Ø5.624 deployed stent in a 0.146-in annulus
  (geometrically impossible; an annulus-fit Belleville is ~2 orders of
  magnitude short on force). Belleville retained as hold-open/anti-recoil only.
- Energy source = **the well**: applied CT pump pressure, or e-line hydrostatic
  gated by a burst disk vs a sealed reference chamber (SHEX-016). Deploy
  pressures (941/470 psi) sit below hydrostatic even at 3000 ft.

**Work done this session:**

- `export/analysis/actuator_design.py` (+ `.json`): annulus budget, expansion
  pressures/forces, bladder sizing, Belleville check, sequence/interlock,
  open items. Numbers: stage-1 deploy ~941 psi / 433 cc; stage-2 ~470 psi /
  1898 cc; radial forces ~20–25 klbf.
- `cad/actuator_solids.py` + `generate_actuators.py`: 7 machined parts
  (SHEX-014A/014B/014C/015B/015C/016/016A) + run-in & deployed sub-assemblies
  (`SHEX-ACT-S12_*`, 20 bodies each). Round-trip verified — every part 1 solid,
  0 orphan surfaces (`export/release/verify_actuators.py`); previews rendered.
- 5 manual figures (`figures_actuators.py`): run-in & deployed sections,
  first-stroke sequence, pressure budget, why-bladder.
- 5 drawings ACT-DWG-014A/014B/014C/015/016 (DXF+PDF).
- `export/release/manual/ACTUATOR_MANUAL.md` (SHEX-MAN-003): design, sizing,
  manufacturing, arming/operation, DCN-10/11, open items.
- RELEASE_NOTES updated (DCN-10/11 + actuator package index).

**Status: session 3 deliverables COMPLETE.** Remaining items are
data-dependent (FEA, full-scale deploy test, burst-disk/orifice selection,
ratchet retrieval kinematics, add charge-port/ratchet-band to SHEX-011
mandrel drawing) and carried in FORWARD_PLAN.

---

## 2026-06-13 — Setting-tool package (continuation)

**Author:** Fable (AI), session 2.

**Context resumed from:** plug release package complete (STEP + drawings +
`export/release/manual/MANUAL.md`). Setting-tool work had been *started* by a
prior session — SHEX-AK-20 adapter kit STEP/DXF existed — but with no working
log, no market comparison, no CT path write-up, and no setting-tool manual.

**Review findings (before starting):**

1. Two parallel setting-tool lines exist in the repo:
   - **Legacy bespoke electromechanical tool** `SHEX-ST-54` (docs
     `First Pass Files/docs/SETTING_TOOL_DETAIL.md`, config
     `export/config/setting_tool_shex_st54.yaml`, analysis
     `export/analysis/setting_tool_design.py`). 246 in, 3.625 OD, motor +
     ball screw, 12 in stroke, 55 klbf. **Status: superseded** — bespoke
     downhole electromechanical setting tools are a multi-year qualified-vendor
     program, not a deliverable here. Kept for reference only.
   - **Commercial-tool adapter kit** `SHEX-AK-20` (`cad/setting_kit_solids.py`,
     `generate_setting_kit.py`, `export/drawings/generate_kit_drawings.py`).
     **Status: active direction** — this is the right answer and what this
     session completes.
2. Adapter kit already generated (verified on disk):
   - Parts ST-101 (setting sleeve/shoe), ST-102 (tension rod), ST-103
     (calibrated shear stud), ST-104 (stroke spacer) — STEP in
     `export/release/step/parts/`.
   - Assemblies `SHEX-AK-20_INTERFACE_RIGGED.stp` (8 bodies) and
     `..._RELEASED.stp` (9 bodies) in `export/release/step/assemblies/`.
   - Drawings ST-DWG-101/102/103 (DXF + PDF).
   - `export/release/manifest_setting_kit.json`.
3. Plug DCN log already carries the settability decisions:
   - **DCN-7** top joint downsized (Ø1.375 pin, Rev E neck Ø1.450 body) so a
     setting sleeve can pass over the neck and land on the upper slip carrier.
   - **DCN-8** net set stroke re-budgeted 11.0 → **10.0 in** (+0.25 overtravel
     = 10.25 demand) to fit a Baker E-4 No. 20 (10.777 in stroke) and #20 CT
     tools; release stud calibrated **45 klbf**.
   - **DCN-9** iris drive interference fix + module re-index.

**Market data captured (this session, web-verified):**

| Tool | Type | Stroke (in) | Max force (lbf) | OD (in) | Notes |
|---|---|---|---|---|---|
| Baker E-4 #05 | e-line, gas | 5.879 | 10,000 | 1.718 | only size that passes 2-3/8 tubing |
| Baker E-4 #10 | e-line, gas | 5.707 | 35,000 | 2.750 (HD 3.800) | 5-in-class plugs |
| **Baker E-4 #20** | e-line, gas | **10.777** | **55,000** | **3.800** (HD 4.125) | **selected interface** |
| Baker Model J #10/#20 | CT hydraulic | matches E-4 | pressure×pistons | = E-4 size | **same adapter kits as E-4** |
| TechWest B20 / Renown B-20 | CT hydraulic | ~10–11 | 50,000 (stud) | 3.8–4.25 | #20 clone, same adapters |
| Pinnacle HST 425 | CT hydraulic | 11 | pressure×pistons | Baker 20 conn | same adapters as E-4 |
| TechWest B105 / Renown B-10 | CT hydraulic | ~6 | low (thru-tubing) | 1.81 | thru-tubing, low force |

Sources: Baker Hughes E-4 technical unit PDF; Owen MAN-SET-E410; RepeatPrecision
Baker-20; Pinnacle, TechWest, MAP, Renown, Alpha product pages.

**Key reconciliation (the stroke story):**

- The plug is a **two-actuator** machine (confirmed in
  `First Pass Files/docs/SETTING_SEQUENCE.md`):
  - **First / internal actuation** — stage-1 bladder (SHEX-014, burst-disk
    fired) and stage-2 Belleville (SHEX-015) expand the two stent stages
    radially. **This does not draw on the setting tool.** This is the
    "first stroke initiated somehow" — it is initiated by the burst disk /
    arming event, *not* by the setting tool.
  - **Secondary / tool stroke (10.0 in)** — the market setting tool's single
    axial stroke completes stage-3 iris + 4 seal lands + dual slips, then
    shears free. A single-stroke pyrotechnic E-4 or a single-stroke CT
    hydraulic tool both satisfy this because the internal stages have already
    fired before the tool strokes.
- **The real market conflict (this session's headline finding):** a tool that
  delivers 45–55 klbf at the #20 interface is ~3.8 in OD and **cannot pass
  through 2-3/8 / 2-7/8 tubing**. Only the E-4 #05 (1.718 in OD) passes
  small tubing, and it makes just 10 klbf / 5.879 in. Therefore:
  - **SHEX-AK-20 (#20) is for deployment in casing or ≥4-1/2 in tubing/liner**
    where a 3.8 in tool can reach setting depth. This is the realistic
    45-klbf solution and the primary deliverable.
  - **Genuine small-tubing thru-tubing setting** (tool OD ≤1.9 in) caps out
    near 10 klbf, which requires the seal/slip system to be *pressure-energized*
    rather than *stroke-energized*. Logged as an open redesign item, not
    resolved here.

**Work done this session:**

- Created this log + `FORWARD_PLAN.md`.
- Market comparison + stroke/force reconciliation captured (tables above).
- Verified SHEX-AK-20 STEP round-trip (ST-101 L15.000, ST-102 L15.100,
  ST-103 L3.200, ST-104 L0.250; each 1 solid, 0 orphan surfaces) and
  re-rendered interface previews.
- Generated 8 manual figures (`figures_setting.py`): run-string GA, rigged &
  released interface sections, two-actuator architecture, market OD-vs-force
  conflict, stroke budget. Fixed label crowding on GA/two-stroke/market plots.
- Wrote setting-tool manual
  `export/release/manual/SETTING_TOOL_MANUAL.md` (SHEX-MAN-002 Rev A):
  Part 0 why-adapter-not-bespoke, Part 1 engineering design (two-actuator),
  Part 2 market selection + OD-vs-force conflict, Part 3 manufacturing,
  Part 4 rig-up/operations (e-line + CT), Part 5 assumptions/open items.

**Status: session 2 deliverables COMPLETE.** Remaining items are
engineering-data dependent (FEA, internal-actuator design, tool-thread
verification) and carried in FORWARD_PLAN.

**Check next:** see FORWARD_PLAN.

---

## (earlier) — Plug release package

Plug STEP (15 parts + 2 assemblies), 14 manufacturing drawings, and
`export/release/manual/MANUAL.md` completed in session 1. DCN-1..6 resolved
spec contradictions; geometry round-trip verified (1 solid/part, 0 orphan
surfaces). See `export/release/RELEASE_NOTES.md`.

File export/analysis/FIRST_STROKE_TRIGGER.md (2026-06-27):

# First-Stroke Trigger & Equalizing-Sleeve Interlock — Design Memo

| | |
|---|---|
| Document | SHEX-EM-001 Rev A (engineering memo) |
| Subject | How the internal "first stroke" is **triggered** and **sequenced** downhole |
| Closes | FORWARD_PLAN open item: *"trigger / equalizing-sleeve interlock referenced but not designed — required for the first stroke to be real."* |
| Numbers | `export/analysis/trigger_design.py` (+ `.json`) |
| Proposes | **DCN-12** (initiation/sequencing re-architecture) + new sub **SHEX-017** |
| Companions | `ACTUATOR_MANUAL.md` (hardware), `SETTING_TOOL_MANUAL.md` (secondary stroke) |

---

## 0. The question, stated honestly

The stage-1/2 actuator **hardware** is designed and modelled (bladders, glands,
lock rings, Belleville hold, charge subs, pilot piston). What was **not** an
engineering design — only a narrative — is the part that actually makes the
first stroke happen at the right place, in the right order, without firing on
the way to depth:

> inherited concept: *"burst disk p1 fires the EQ pilot first, then stage-1
> disk at p1, then a 30 s metering orifice, then stage-2 disk at p2 > p1."*

If the first stroke isn't a **real, position-correct, ordered, fail-safe**
event, the whole two-stroke architecture is just a drawing. So this memo
pressure-tests that concept and replaces it.

---

## 1. Why the inherited concept cannot work (the fatal flaw)

A burst disk referenced to a sealed/atmospheric chamber responds to **absolute
hydrostatic**. Hydrostatic **rises continuously as you run in**, so the disk
fires at the depth where hydrostatic = its crack pressure — **on the way down,
not at target depth.**

`trigger_design.py` §1, 9.0 ppg:

| Depth | Hydrostatic | vs p1 = 941 psi | vs p2 = 470 psi |
|---|---|---|---|
| 1000 ft | 468 psi | ok | ok |
| 2000 ft | 936 psi | ok | **FIRES** |
| 3000 ft | 1404 psi | **FIRES** | **FIRES** |
| 8000 ft | 3744 psi | **FIRES** | **FIRES** |

**There is no single absolute-pressure setting that both survives run-in to a
deep target and fires only at target depth.** Set the disk high enough to
survive run-in and the hydrostatic at depth is too low to ever fire it; set it
low enough to fire and it trips during descent. Passive hydrostatic triggering
has **no position control** — this is fatal, not a tuning problem.

Three more problems fall out of the same root:

1. **Order isn't enforced.** p1 and p2 are only a few hundred psi (a few hundred
   feet) apart, so on a continuous run-in both "sequence" thresholds are crossed
   within seconds. A metering orifice delays *bladder fill*, not the *trigger* —
   with hydrostatic always present, both stages fire essentially together.
2. **Volume.** Stage 2 needs ~1898 cc. No self-contained downhole chamber that
   fits a 0.146-in annulus can store that volume of pressurised fluid; the
   **well** must supply it — which drags hydrostatic back into the trigger.
3. **No defined fail state.** If the sequence half-completes there's no stated
   safe/recoverable condition.

---

## 2. The fix — separate the three things the old concept conflated

| | What it is | Old concept (conflated) | New (DCN-12) |
|---|---|---|---|
| **Energy / volume** | what inflates the bladders | hydrostatic via disk | **the well** (CT pump fluid, or hydrostatic) — unchanged source, but *gated* |
| **Initiation** | what starts it, *when* | absolute pressure threshold | a **deliberate operator command** that is position-correct |
| **Sequencing** | EQ → S1 → S2 order | pressure thresholds + time orifice | **mechanical: each stage's completion enables the next** |

Once you stop asking one passive pressure threshold to do all three jobs, each
job has a clean, defensible solution.

---

## 3. Initiation — position-correct, run-in-safe, by conveyance

Both conveyances feed a **common sequence manifold** (new sub **SHEX-017**); the
*front end* differs, everything downstream of the gate is identical.

### 3.1 Coiled tubing — applied differential (depth-independent)

Operator pumps the CT bore to **hydrostatic + ~1500 psi** at depth. A reference
piston with **CT bore on one face and annulus on the other** responds only to
the *applied differential*, so depth/hydrostatic cancel:

| Depth | Annulus | Trigger pressure | vs bladder rating 2500 |
|---|---|---|---|
| 2000 ft | 936 psi | 2436 psi (always +1500) | ok |
| 8000 ft | 3744 psi | 5244 psi | ok (CT bore handles it) |
| 12000 ft | 5616 psi | 7116 psi | ok |

A **ball/dart seat** is added as a positive arm: nothing in the manifold can
move until the ball lands, so run-in and circulating pressures are mechanically
locked out. This is standard CT inflatable-packer / hydraulic-set practice.

### 3.2 Electric wireline — fire the gate, let hydrostatic fill

E-line has no flow path and a charge cannot supply 1898 cc. So split it:

- a **small EFI/igniter** (the same class of initiator the Baker E-4 already
  uses) **opens the gate on command** — total position control;
- **wellbore hydrostatic** then supplies the large volume to inflate.

Hydrostatic must exceed the deploy demand at set depth (p1 = 941 psi): true at
**≥ ~2000 ft / 9 ppg** and deeper. Shallow or under-balanced sets fall back to
the documented **gas-generator boost** option.

> This mirrors how the secondary-stroke tool already works on e-line (a
> command-fired power charge), so the conveyance crew uses one familiar
> initiation model for both strokes.

---

## 4. Sequencing — completion-gated, not threshold/time

This is the heart of the interlock. Instead of trusting pressure magnitude or a
timer, **each stage's completion physically arms the next**, using the
expansion's own **pressure signature**:

1. While a stent is still opening, bladder pressure sits at its **deploy
   plateau** (~941 psi stage 1) — work is being done hinging the mesh.
2. When the stent hits its **hard stop** (fully open), no more volume is
   accepted and pressure **climbs from the plateau toward source**.
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

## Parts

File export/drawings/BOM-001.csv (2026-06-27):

Item | Part No | Description | Material | Qty | Notes
1 | SHEX-001 | Iris segment | 17-4 PH H900 | 16 | DWG-001, t=0.187
2 | SHEX-002 | Helix guide mandrel | Inconel 718 | 1 | Double-start 4in lead
3 | SHEX-003 | MTM ring segment | 17-4 PH H900 | 12 | DWG-005
4 | SHEX-004 | HNBR seal land | HNBR 90 duro | 4 | DWG-007, 4.5in axial each
5 | SHEX-005 | Petal backup | 17-4 PH | 64 | DWG-007, 16 per seal land
6 | SHEX-006 | Upper slip segment | 17-4 PH | 8 | DWG-008, 9-5/8 casing
7 | SHEX-007 | Lower slip segment | 17-4 PH | 8 | DWG-008, 9-5/8 casing
8 | SHEX-008 | Stage 1 stent sleeve | 17-4 PH | 1 | DWG-009, laser cut
9 | SHEX-009 | Stage 2 stent sleeve | 17-4 PH | 1 | DWG-011, laser cut
10 | SHEX-010 | Stage 3 iris support sleeve | 17-4 PH | 1 | DWG-012
11 | SHEX-011 | Inner mandrel | 17-4 PH | 1 | Through bore
12 | SHEX-012 | Top sub / fishing neck | 4140 | 1 | DWG-010, 1.375 AMMT
13 | SHEX-013 | Bottom equalizing sub | 4140 | 1 | Ported
14 | SHEX-014 | Expansion bladder | HNBR | 1 | Stage 1
15 | SHEX-015 | Belleville stack | Inconel 718 | 1 | Stage 2
16 | ST-001 | Setting tool assembly | 4140/17-4 | 1 | DWG-004, per run

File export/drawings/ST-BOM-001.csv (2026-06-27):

Item | Part No | Description | Qty | Make/Buy | Drawing | STEP | Example vendor / source | Example P/N or spec | Notes
1 | ST-001 | Bottom crossover AMMT housing | 1 | MACHINE | ST-DWG-001 | ST_crossover.stp | Local machine shop | 4140 HT per drawing | O-Rings Parker Viton
2 | ST-002 | Release collet assembly | 1 | MACHINE | ST-DWG-002 | ST_release.stp | Local machine shop | 17-4 PH H900 | Includes shear pins
3 | ST-003 | Pressure balance module | 1 | MACHINE | ST-DWG-003 | ST_pressure.stp | Local machine shop | 17-4 PH + piston seals Trelleborg | 20 ksi rated
4 | ST-004 | Stroke actuator housing | 1 | MACHINE | ST-DWG-004 | ST_stroke.stp | Local machine shop | 17-4 PH H900 | Ball screw purchased separately
5 | ST-005 | Load cell section housing | 1 | MACHINE | ST-DWG-005 | ST_loadcell.stp | Local machine shop | 17-4 PH | Contains purchased load cell
6 | ST-006 | Motor/gearbox housing | 1 | MACHINE | ST-DWG-006 | ST_motor.stp | Local machine shop | 17-4 PH | Motor/gearbox purchased
7 | ST-007 | Battery housing (dual module) | 1 | MACHINE | ST-DWG-007 | ST_battery.stp | Local machine shop | Ti or 17-4 PH | Cells purchased separately
8 | ST-008 | Telemetry cartridge housing | 1 | MACHINE | ST-DWG-008 | ST_telemetry.stp | Local machine shop | 17-4 PH | PCB assembly separate
9 | ST-009 | Cable head / CCL sub | 1 | MACHINE | ST-DWG-009 | ST_head.stp | Local machine shop | 4140 HT | Rope socket per cable size
10 | ST-010 | Inner stroke push mandrel | 1 | MACHINE | ST-DWG-010 | ST_inner_stroke_mandrel.stp | Local machine shop | 17-4 PH H900 H1150M | Hard chrome contact zone
11 | ST-COTS-001 | Ball screw assembly | 1 | BUY | ST-DWG-004 | — | Thomson (Altra) | 6409KAA x custom length | 0.500 in lead; 55 klbf rating
12 | ST-COTS-002 | Linear bearings (pair) | 2 | BUY | ST-DWG-004 | — | Thomson | 60 Case standard x custom | Inside stroke module
13 | ST-COTS-003 | Load cell | 1 | BUY | ST-DWG-005 | — | Interface Force Measurement | 1200 Standard (trimmed) | 350 ohm bridge
14 | ST-COTS-004 | BLDC motor | 1 | BUY | ST-DWG-006 | — | Maxon Motor | EC-i 40 brushless | Lab prototype
15 | ST-COTS-005 | Planetary gearbox | 1 | BUY | ST-DWG-006 | — | Maxon Motor | GP 42 HP | Reduction per torque calc
16 | ST-COTS-006 | Rotary encoder | 1 | BUY | ST-DWG-006 | — | US Digital | E5 2048 CPR | Motor feedback
17 | ST-COTS-007 | Li-SOCl2 D cell | 48 | BUY | ST-DWG-007 | — | Saft or Tadiran | LS14500 / TL-5903 | Primary non-rechargeable
18 | ST-COTS-008 | Battery fuse holder | 2 | BUY | ST-DWG-007 | — | Littelfuse | 471 series | Redundant isolation
19 | ST-COTS-009 | MCU board (lab) | 1 | BUY | ST-DWG-008 | — | Texas Instruments | MSP430FR5994 launchpad adapted | Production: wireline telemetry vendor
20 | ST-COTS-010 | Flash memory | 1 | BUY | ST-DWG-008 | — | Industrial SD or SPI flash | 128 MB min | Force/stroke curve storage
21 | ST-COTS-011 | Downhole pressure transducer | 1 | BUY | ST-DWG-008 | — | Keller AG | 10LHPX 0-20 ksi | Oil-filled housing
22 | ST-COTS-012 | Temperature sensor | 1 | BUY | ST-DWG-008 | — | Various | PT100 Class A RTD | In telemetry bore
23 | ST-COTS-013 | LVDT stroke sensor | 1 | BUY | ST-DWG-008 | — | Macro Sensors | CD375 custom stroke | 12 in travel
24 | ST-COTS-014 | Wireline telemetry modem | 1 | BUY | ST-DWG-008 | — | Glenair + custom | 805 series connector | RS-485 or proprietary WL
25 | ST-COTS-015 | CCL mandrel magnet | 1 | BUY | ST-DWG-009 | — | Scout Downhole / custom | SDCCL-3625 class | Optional depth correlation
26 | ST-COTS-016 | O-ring kit (tool) | 1 | BUY | All | — | Parker / Apple Rubber | Viton 90 duro | Per groove chart in ST-DWG-001/003
27 | ST-COTS-017 | Shear pins | 8 | BUY | ST-DWG-002 | — | McMaster-Carr | 90107A195 (17-4 PH 0.125 dia) | Replace after each set
28 | ST-COTS-018 | Belleville spring stack | 1 | BUY | ST-DWG-002 | — | Spirol / Associated Spring | Custom stack | Release collet preload

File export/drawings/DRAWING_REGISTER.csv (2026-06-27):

Seq | Part No | Description | Tier | Drawing No | STEP file | Schematic DXF | Fusion action | Status | Priority
01 | SHEX-012 | Fishing neck / top sub | MANUFACTURING | DWG-010-SHP | export/cad/parts/SHEX-012_fishing_neck.stp | DWG-010_fishing_neck.dxf | Model Rev D → shop drawing @ OD 1.688 max | SHOP READY | 1
02 | SHEX-013 | Bottom equalizing sub | MANUFACTURING | DWG-013-SHP | export/cad/parts/SHEX-013_bottom_equalizing_sub.stp | — | DEFERRED — iris stack first | PENDING | 4
03 | SHEX-011A | Mandrel tail sleeve | MANUFACTURING | DWG-011A-SHP | export/cad/parts/SHEX-011_mandrel_tail_sleeve.stp | part_specs/SHEX-011A_mandrel_tail_sleeve.md | Import STEP → shop drawing | PENDING | 1
04 | SHEX-011 | Inner mandrel (full) | MANUFACTURING | DWG-011B-SHP | export/cad/parts/SHEX-011_inner_mandrel.stp | part_specs/SHEX-011_inner_mandrel.md | Steps 1–22 + thread; all OD ≤ 1.688 | SHOP READY | 1
05 | SHEX-002 | Helix guide | MANUFACTURING | DWG-002A-SHP | — | DWG-002_iris_module_assy.dxf | part_specs/SHEX-002_helix_guide.md — iris stack order 2 | IN PROGRESS | 1
06 | SHEX-010 | Stage 3 iris support sleeve | MANUFACTURING | DWG-012-SHP | export/cad/parts/SHEX-010_stage3_support.stp | DWG-012_stage3_iris_support_sleeve.dxf | part_specs/SHEX-010_support_sleeve.md — OD 1.688 order 1 | IN PROGRESS | 1
07 | SHEX-001 | Iris segment (×16) | MANUFACTURING | DWG-001-SHP | export/cad/parts/SHEX-001_iris_segment.stp | DWG-001_iris_segment.dxf | part_specs/SHEX-001_iris_segment.md — iris stack order 3 | IN PROGRESS | 1
08 | — | Stage 3 iris module assy | SET-ILLUSTRATION | DWG-002-SET | — | DWG-002_iris_module_assy.dxf | Virtual assy — deployed OD 8.650; references -SHP parts | PENDING | 2
09 | SHEX-003 | MTM ring segment (×12) | MANUFACTURING | DWG-005-SHP | — | DWG-005_mtm_ring_segment.dxf | Segment arc shop drawing — not full 8.80 ring OD | PENDING | 3
10 | SHEX-006 | Upper slip segment (×8) | MANUFACTURING | DWG-008A-SHP | — | DWG-008_slip_segment.dxf | One wedge shop drawing | PENDING | 3
11 | SHEX-007 | Lower slip segment (×8) | MANUFACTURING | DWG-008B-SHP | — | DWG-008_slip_segment.dxf | One wedge shop drawing | PENDING | 3
12 | SHEX-005 | Petal backup (×64) | MANUFACTURING | DWG-007A-SHP | — | DWG-007_seal_land_module.dxf | part_specs/SHEX-005_petal_backup.md — build_SHEX_005_petal_backup | IN PROGRESS | 3
13 | SHEX-004 | HNBR seal land (×4) | MANUFACTURING | DWG-007B-SHP | — | DWG-007_seal_land_module.dxf | part_specs/SHEX-004_hnbr_seal_land.md — build_SHEX_004_hnbr_seal_land | IN PROGRESS | 4
14 | SHEX-008 | Stage 1 stent sleeve | MANUFACTURING | DWG-009-SHP | export/cad/parts/SHEX-008_stage1.stp | DWG-009_stage1_stent_sleeve.dxf | Laser flat pattern — crimped to 1.688 run-in | PENDING | 4
15 | SHEX-009 | Stage 2 stent sleeve | MANUFACTURING | DWG-011-SHP | export/cad/parts/SHEX-009_stage2.stp | DWG-011_stage2_stent_sleeve.dxf | Laser flat pattern — crimped to 1.688 run-in | PENDING | 4
16 | SHEX-014 | Expansion bladder | MANUFACTURING | — | — | — | Vendor / mold spec only | PENDING | 5
17 | SHEX-015 | Belleville stack | MANUFACTURING | — | — | — | Vendor stack spec only | PENDING | 5
18 | — | Plug assembly GA | SET-ILLUSTRATION | DWG-003-SET | export/cad/step/plug_set_assembly.stp | DWG-003_plug_54in_GA.dxf | Full plug set condition — not for machining | PENDING | 5
19 | — | Plug run-in vs set | SET-ILLUSTRATION | DWG-006-SET | export/cad/step/plug_run_in_assembly.stp | DWG-006_prototype_whole_tool_detailed.dxf | Comparison / training illustration | PENDING | 5
20 | ST-001 | Setting tool crossover | MANUFACTURING | DWG-ST-001-SHP | export/cad/parts/setting_tool/ST_crossover.stp | ST-DWG-001 | Shop drawing | PENDING | 2
21 | ST-002 | Release collet | MANUFACTURING | DWG-ST-002-SHP | export/cad/parts/setting_tool/ST_release.stp | ST-DWG-002 | Shop drawing | PENDING | 2
22 | ST-003 | Pressure balance | MANUFACTURING | DWG-ST-003-SHP | export/cad/parts/setting_tool/ST_pressure.stp | ST-DWG-003 | Shop drawing | PENDING | 2
23 | ST-004 | Stroke actuator | MANUFACTURING | DWG-ST-004-SHP | export/cad/parts/setting_tool/ST_stroke.stp | ST-DWG-004 | Shop drawing | PENDING | 1
24 | ST-005 | Load cell section | MANUFACTURING | DWG-ST-005-SHP | export/cad/parts/setting_tool/ST_loadcell.stp | ST-DWG-005 | Shop drawing | PENDING | 3
25 | ST-006 | Motor / gearbox | MANUFACTURING | DWG-ST-006-SHP | export/cad/parts/setting_tool/ST_motor.stp | ST-DWG-006 | Shop drawing | PENDING | 3
26 | ST-007 | Battery housing | MANUFACTURING | DWG-ST-007-SHP | export/cad/parts/setting_tool/ST_battery.stp | ST-DWG-007 | Shop drawing | PENDING | 3
27 | ST-008 | Telemetry cartridge | MANUFACTURING | DWG-ST-008-SHP | export/cad/parts/setting_tool/ST_telemetry.stp | ST-DWG-008 | Shop drawing | PENDING | 3
28 | ST-009 | Cable head / CCL | MANUFACTURING | DWG-ST-009-SHP | export/cad/parts/setting_tool/ST_head.stp | ST-DWG-009 | Shop drawing | PENDING | 2
29 | ST-010 | Inner stroke mandrel | MANUFACTURING | DWG-ST-010-SHP | export/cad/parts/setting_tool/ST_inner_stroke_mandrel.stp | ST-DWG-010 | Shop drawing | PENDING | 1
30 | — | Setting tool assembly GA | SET-ILLUSTRATION | DWG-004-SET | export/cad/step/setting_tool_SHEX-ST-54.stp | DWG-004_setting_tool_SHEX-ST-54.dxf | Tool layout illustration | PENDING | 5

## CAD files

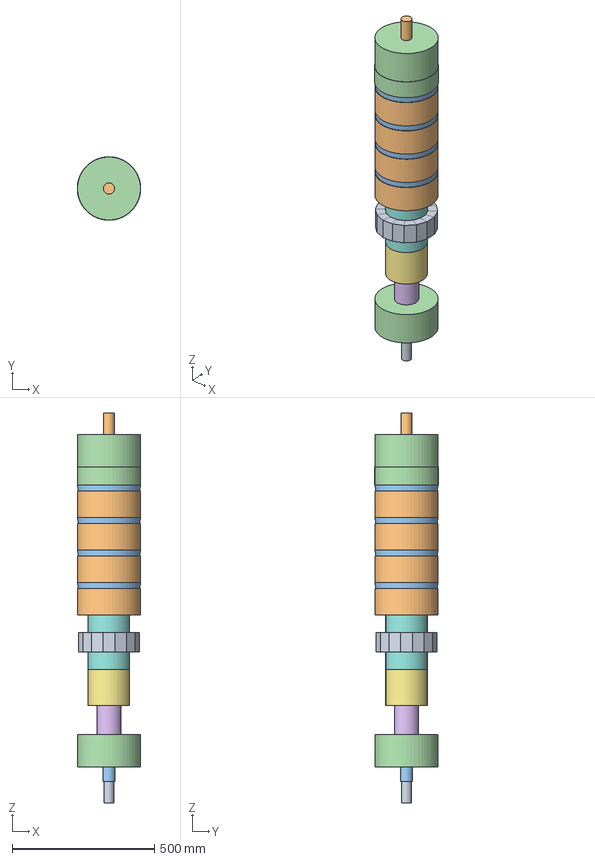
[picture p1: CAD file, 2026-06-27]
export/cad/step/plug_set_assembly.stp
223.3 x 223.4 x 1371.6 mm

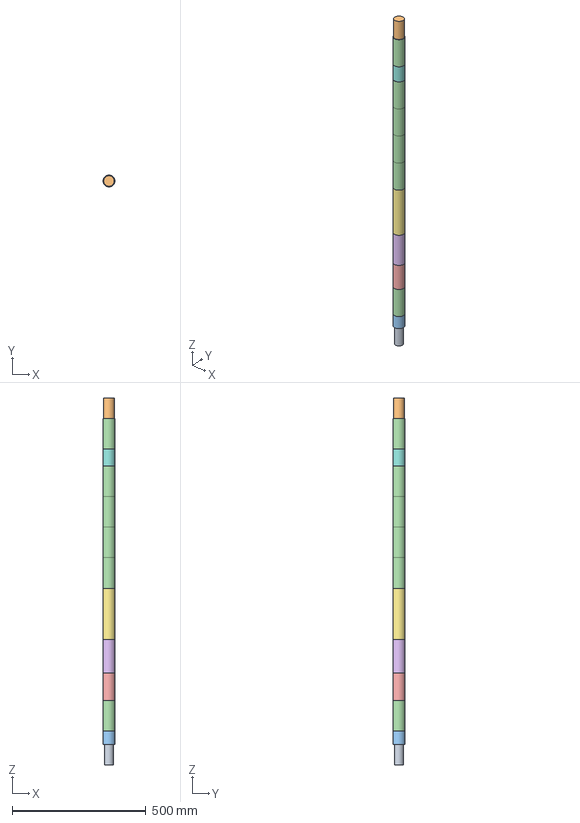
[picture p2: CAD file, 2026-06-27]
export/cad/step/plug_run_in_assembly.stp
44.4 x 44.4 x 1371.6 mm

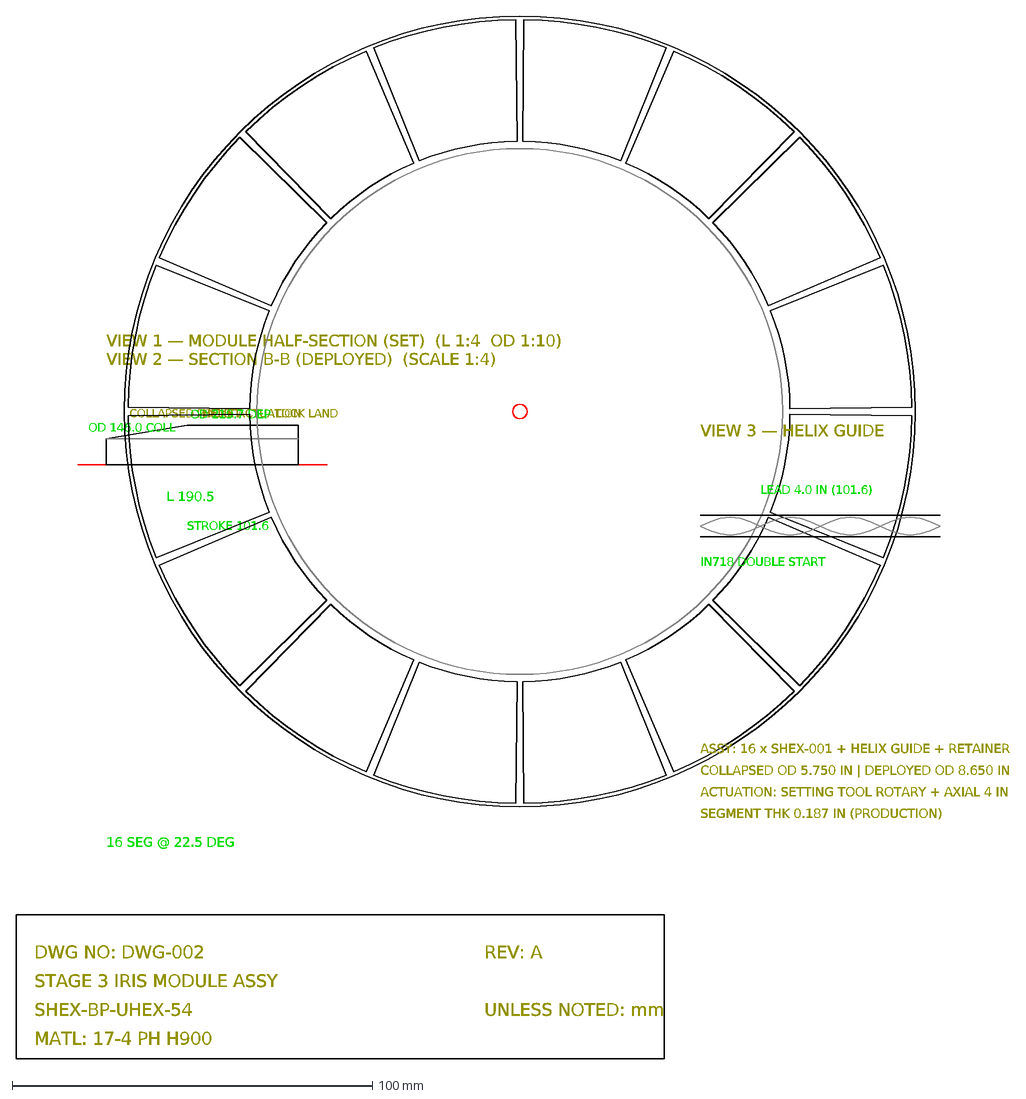
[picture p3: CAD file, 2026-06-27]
export/drawings/dxf/DWG-002_iris_module_assy.dxf
DWG NO: DWG-002
STAGE 3 IRIS MODULE ASSY
SHEX-BP-UHEX-54
REV: A
UNLESS NOTED: mm
MATL: 17-4 PH H900
VIEW 1 — MODULE HALF-SECTION (SET) (L 1:4 OD 1:10)
COLLAPSED POCKET
HELIX ACTUATION
LOCK LAND
L 190.5
OD 146.0 COLL
OD 219.7 DEP
STROKE 101.6
VIEW 2 — SECTION B-B (DEPLOYED) (SCALE 1:4)
16 SEG @ 22.5 DEG
VIEW 3 — HELIX GUIDE
IN718 DOUBLE START
LEAD 4.0 IN (101.6)
ASSY: 16 x SHEX-001 + HELIX GUIDE + RETAINER
COLLAPSED OD 5.750 IN | DEPLOYED OD 8.650 IN
ACTUATION: SETTING TOOL ROTARY + AXIAL 4 IN
SEGMENT THK 0.187 IN (PRODUCTION)

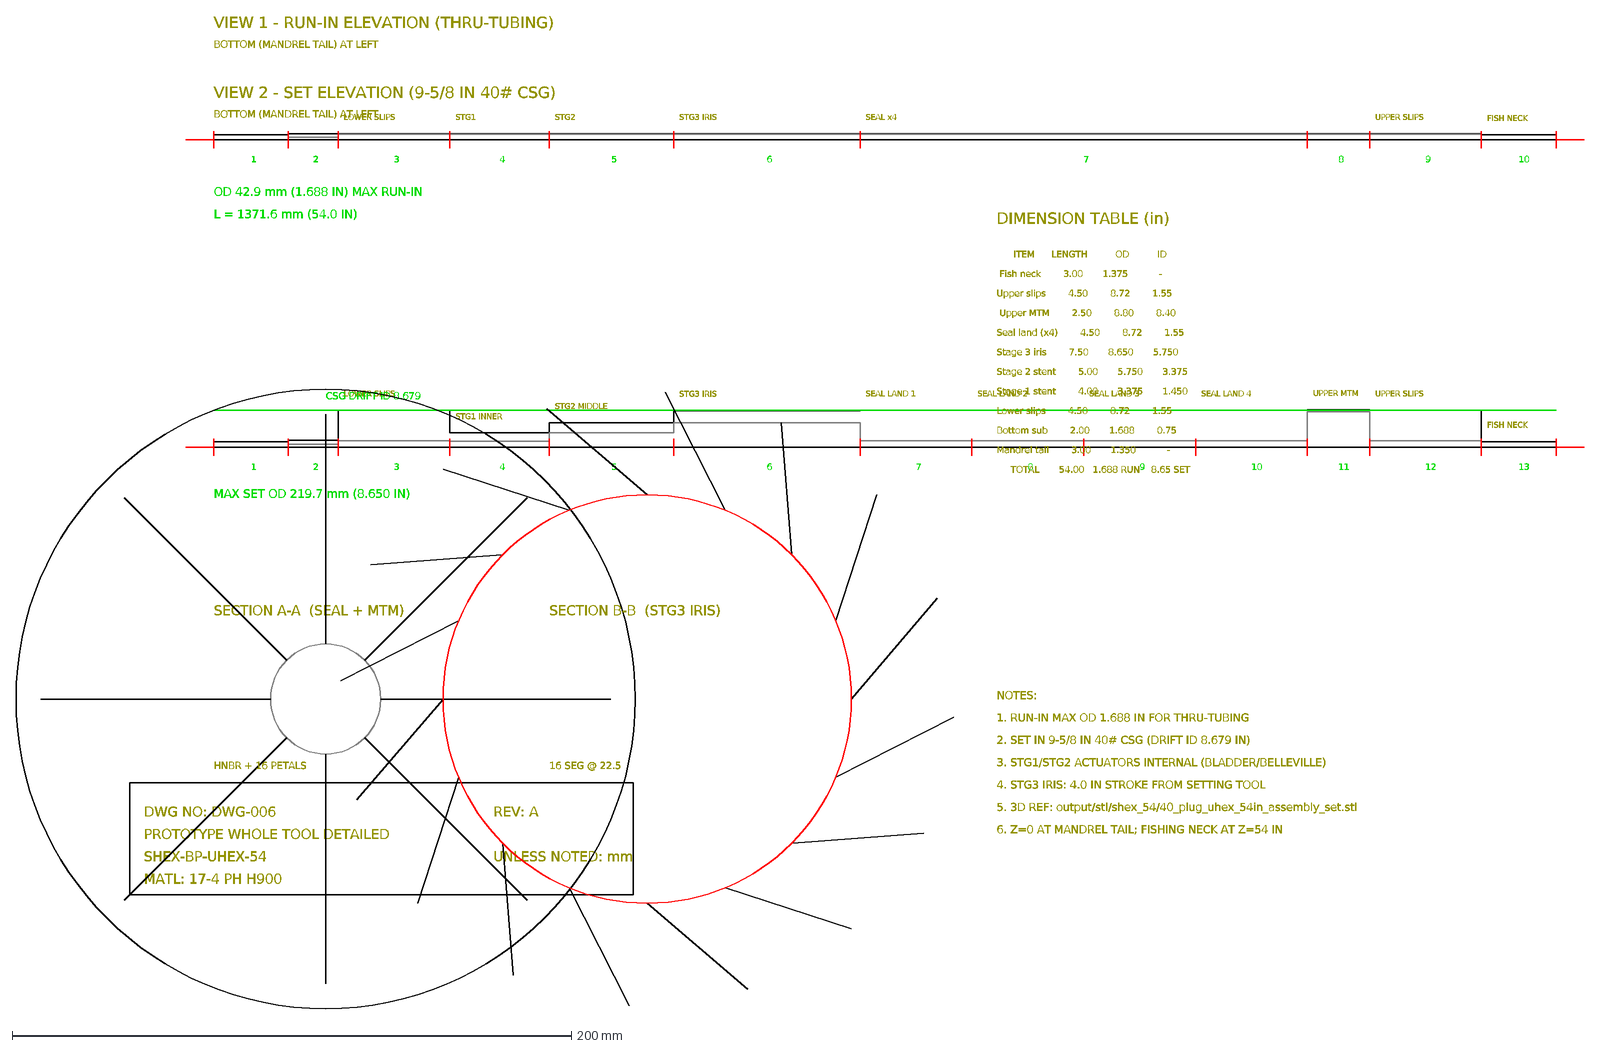
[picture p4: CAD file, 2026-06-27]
export/drawings/dxf/DWG-006_prototype_whole_tool_detailed.dxf
DWG NO: DWG-006
PROTOTYPE WHOLE TOOL DETAILED
SHEX-BP-UHEX-54
REV: A
UNLESS NOTED: mm
MATL: 17-4 PH H900
VIEW 1 - RUN-IN ELEVATION (THRU-TUBING)
BOTTOM (MANDREL TAIL) AT LEFT
1
2
LOWER SLIPS
3
STG1
4
STG2
5
STG3 IRIS
6
SEAL x4
7
8
UPPER SLIPS
9
FISH NECK
10
OD 42.9 mm (1.688 IN) MAX RUN-IN
L = 1371.6 mm (54.0 IN)
VIEW 2 - SET ELEVATION (9-5/8 IN 40# CSG)
STG1 INNER
STG2 MIDDLE
SEAL LAND 1
SEAL LAND 2
SEAL LAND 3
SEAL LAND 4
UPPER MTM
11
12
13
CSG DRIFT ID 8.679
MAX SET OD 219.7 mm (8.650 IN)
SECTION A-A (SEAL + MTM)
HNBR + 16 PETALS
SECTION B-B (STG3 IRIS)
16 SEG @ 22.5
DIMENSION TABLE (in)
ITEM LENGTH OD ID
Fish neck 3.00 1.375 -
Upper slips 4.50 8.72 1.55
Upper MTM 2.50 8.80 8.40
Seal land (x4) 4.50 8.72 1.55
Stage 3 iris 7.50 8.650 5.750
Stage 2 stent 5.00 5.750 3.375
Stage 1 stent 4.00 3.375 1.450
Lower slips 4.50 8.72 1.55
Bottom sub 2.00 1.688 0.75
Mandrel tail 3.00 1.350 -
TOTAL 54.00 1.688 RUN 8.65 SET
NOTES:
1. RUN-IN MAX OD 1.688 IN FOR THRU-TUBING
2. SET IN 9-5/8 IN 40# CSG (DRIFT ID 8.679 IN)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

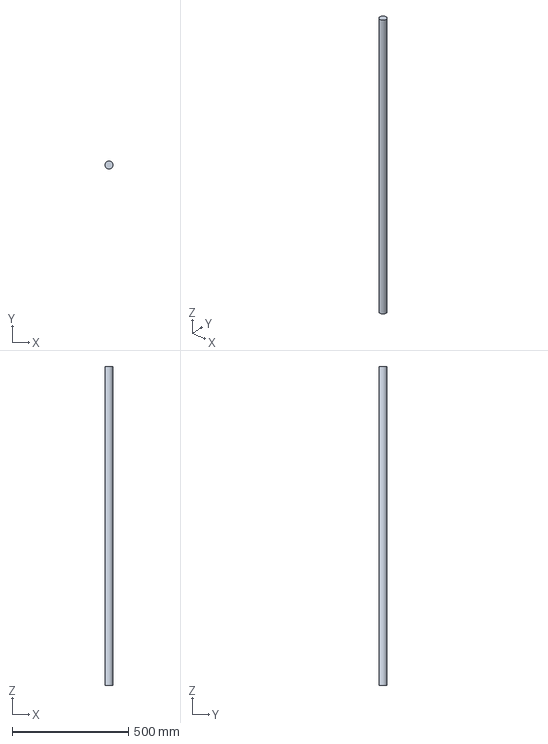
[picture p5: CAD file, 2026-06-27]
export/ansys/step/mandrel_54in_mm.stp
34.3 x 34.3 x 1371.6 mm

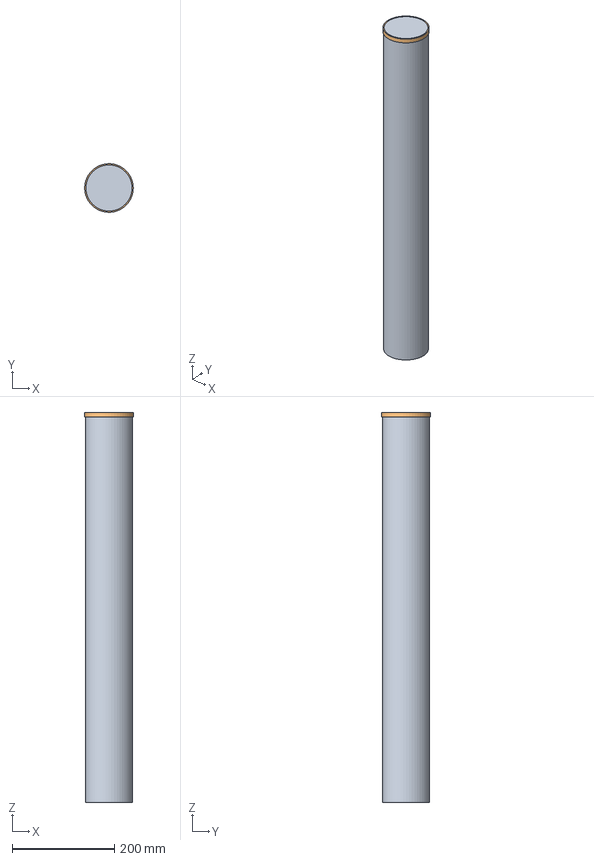
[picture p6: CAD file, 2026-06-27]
export/cad/parts/setting_tool/ST_motor.stp
95.0 x 95.1 x 762.0 mm

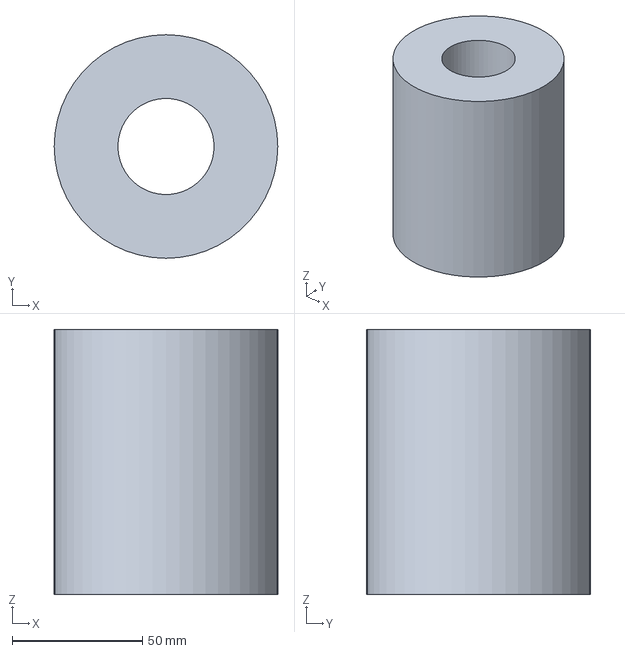
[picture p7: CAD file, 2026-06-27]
export/cad/parts/SHEX-008_stage1.stp
85.7 x 85.7 x 101.6 mm

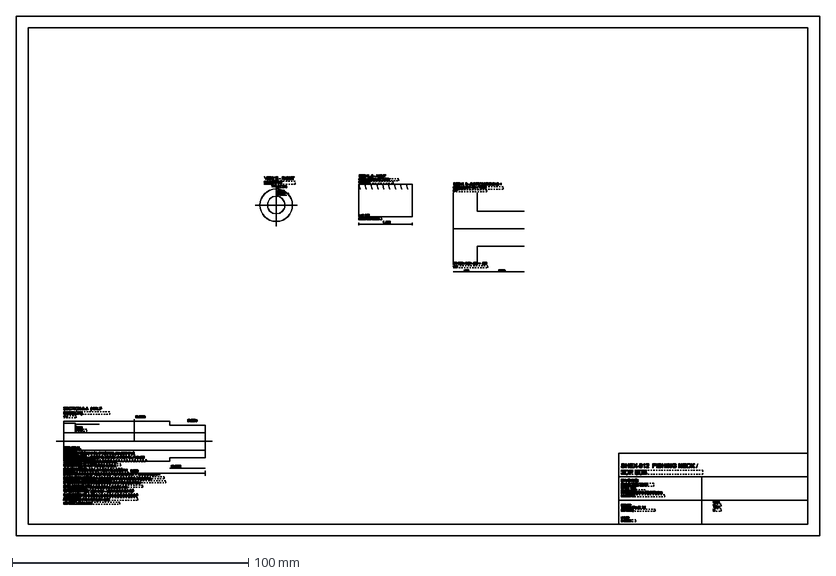
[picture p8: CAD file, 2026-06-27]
export/cad/step/DWG-010-SHP_SHEX-012.dxf
340.0 x 220.0 mm

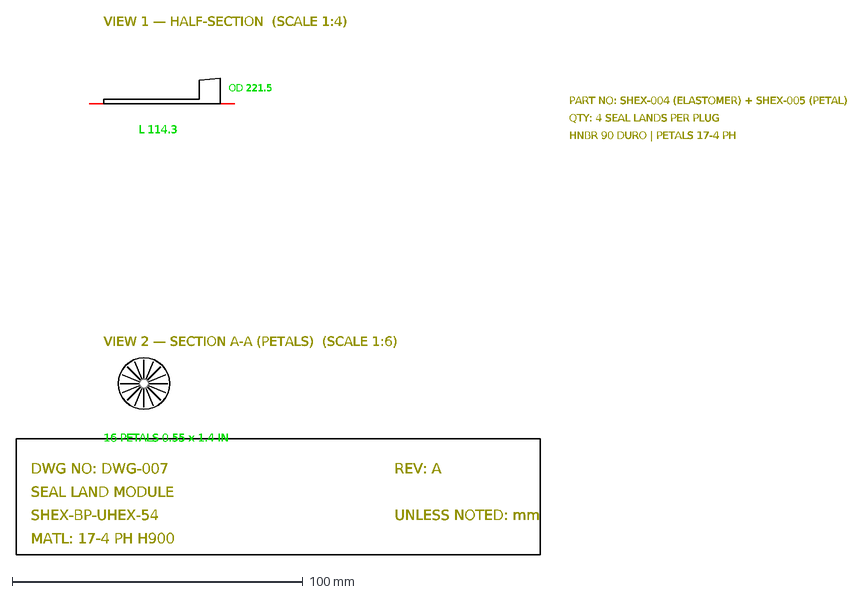
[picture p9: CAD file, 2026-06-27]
export/drawings/dxf/DWG-007_seal_land_module.dxf
DWG NO: DWG-007
SEAL LAND MODULE
SHEX-BP-UHEX-54
REV: A
UNLESS NOTED: mm
MATL: 17-4 PH H900
VIEW 1 — HALF-SECTION (SCALE 1:4)
L 114.3
OD 221.5
VIEW 2 — SECTION A-A (PETALS) (SCALE 1:6)
16 PETALS 0.55 x 1.4 IN
PART NO: SHEX-004 (ELASTOMER) + SHEX-005 (PETAL)
QTY: 4 SEAL LANDS PER PLUG
HNBR 90 DURO | PETALS 17-4 PH

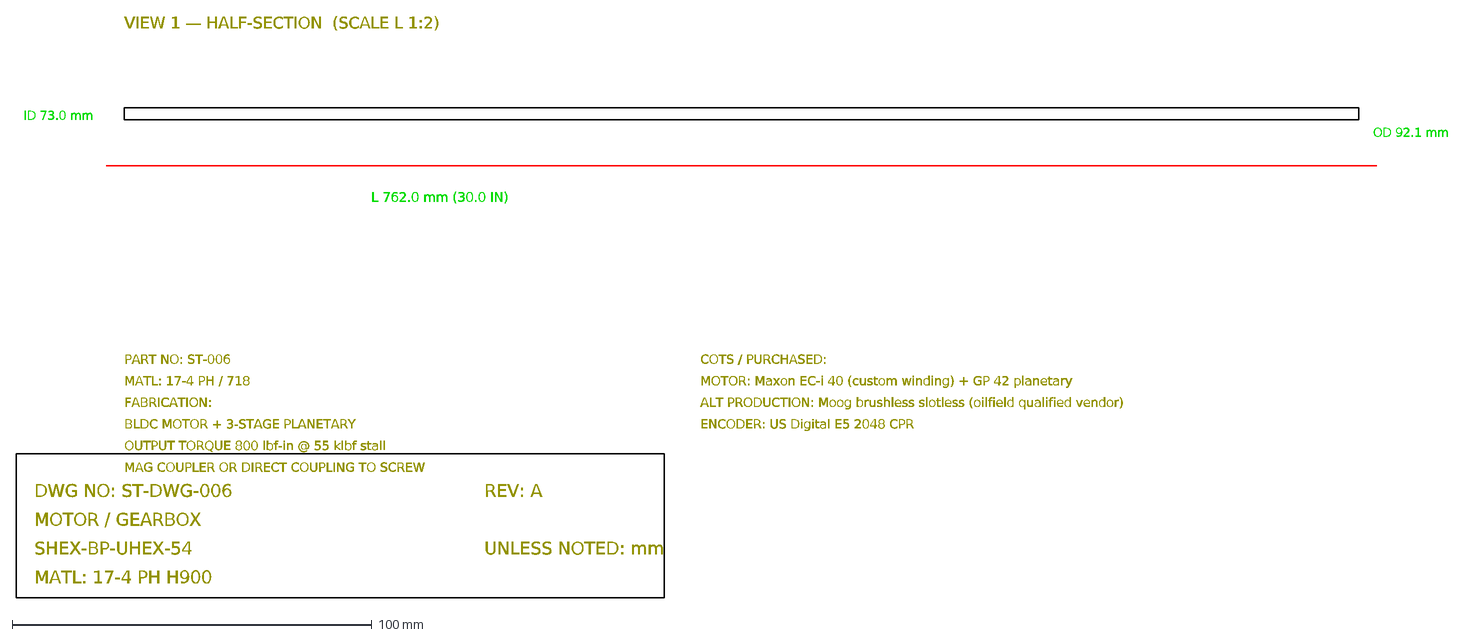
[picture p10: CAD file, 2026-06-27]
export/drawings/dxf/setting_tool/ST-DWG-006_ST-006_MOTOR___GEARBOX.dxf
DWG NO: ST-DWG-006
MOTOR / GEARBOX
SHEX-BP-UHEX-54
REV: A
UNLESS NOTED: mm
MATL: 17-4 PH H900
VIEW 1 — HALF-SECTION (SCALE L 1:2)
L 762.0 mm (30.0 IN)
OD 92.1 mm
ID 73.0 mm
PART NO: ST-006
MATL: 17-4 PH / 718
FABRICATION:
BLDC MOTOR + 3-STAGE PLANETARY
OUTPUT TORQUE 800 lbf-in @ 55 klbf stall
MAG COUPLER OR DIRECT COUPLING TO SCREW
COTS / PURCHASED:
MOTOR: Maxon EC-i 40 (custom winding) + GP 42 planetary
ALT PRODUCTION: Moog brushless slotless (oilfield qualified vendor)
ENCODER: US Digital E5 2048 CPR

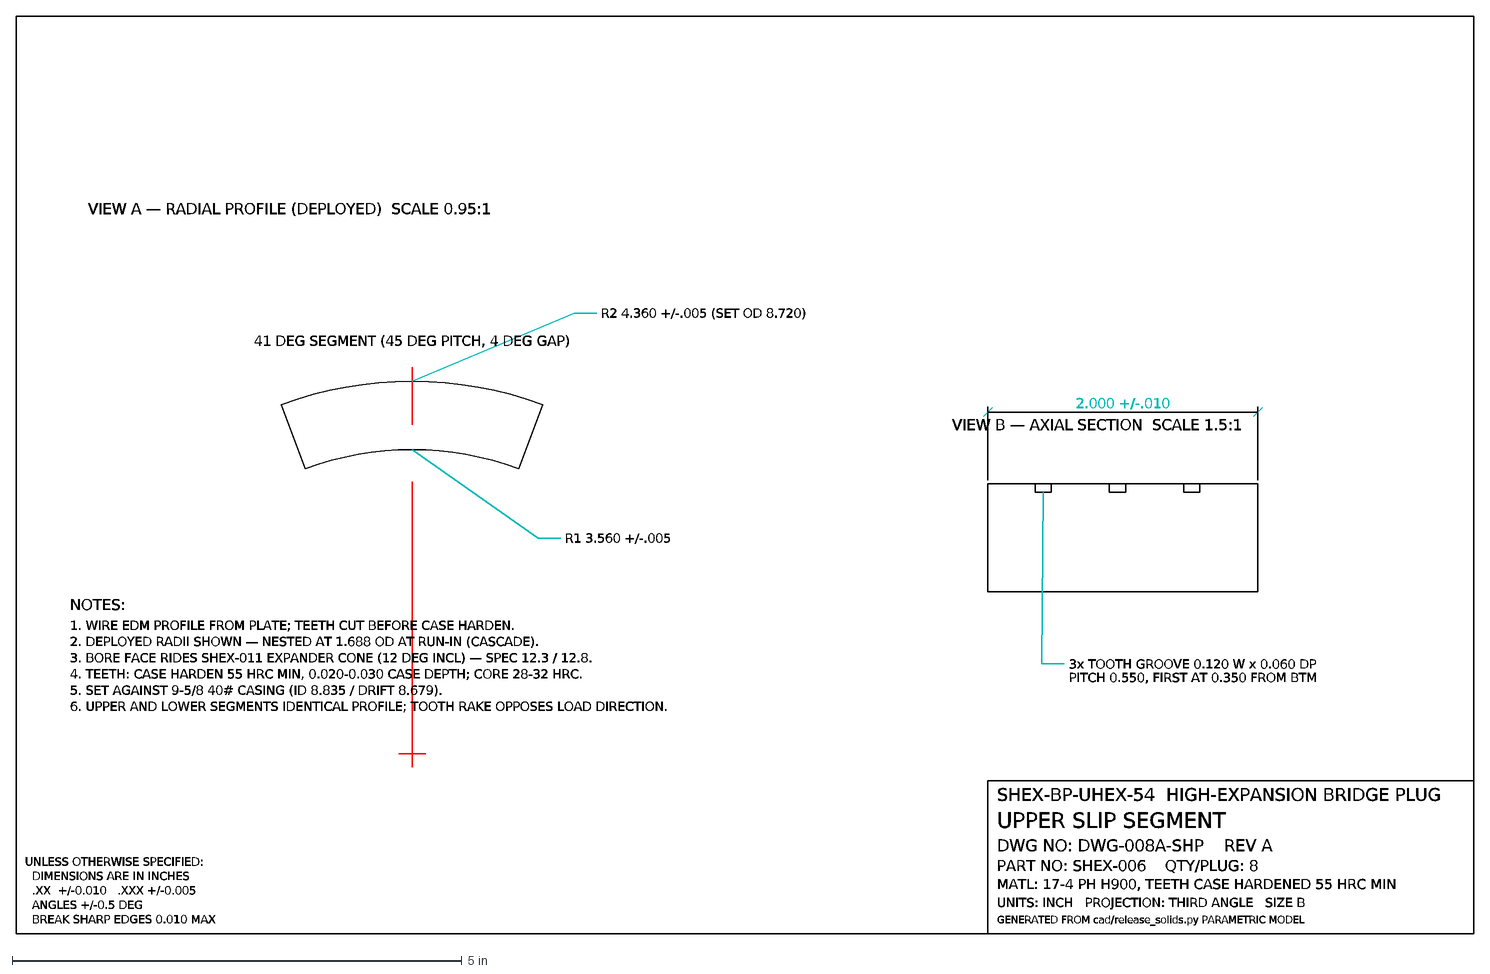
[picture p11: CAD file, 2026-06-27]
export/release/drawings/dxf/DWG-008A-SHP_SHEX-006_slip_segment.dxf
SHEX-BP-UHEX-54 HIGH-EXPANSION BRIDGE PLUG
UPPER SLIP SEGMENT
DWG NO: DWG-008A-SHP REV A
PART NO: SHEX-006 QTY/PLUG: 8
MATL: 17-4 PH H900, TEETH CASE HARDENED 55 HRC MIN
UNITS: INCH PROJECTION: THIRD ANGLE SIZE B
GENERATED FROM cad/release_solids.py PARAMETRIC MODEL
BREAK SHARP EDGES 0.010 MAX
ANGLES +/-0.5 DEG
.XX +/-0.010 .XXX +/-0.005
DIMENSIONS ARE IN INCHES
UNLESS OTHERWISE SPECIFIED:
VIEW A — RADIAL PROFILE (DEPLOYED) SCALE 0.95:1
R1 3.560 +/-.005
R2 4.360 +/-.005 (SET OD 8.720)
41 DEG SEGMENT (45 DEG PITCH, 4 DEG GAP)
VIEW B — AXIAL SECTION SCALE 1.5:1
2.000 +/-.010
3x TOOTH GROOVE 0.120 W x 0.060 DP
PITCH 0.550, FIRST AT 0.350 FROM BTM
NOTES:
1. WIRE EDM PROFILE FROM PLATE; TEETH CUT BEFORE CASE HARDEN.
2. DEPLOYED RADII SHOWN — NESTED AT 1.688 OD AT RUN-IN (CASCADE).
3. BORE FACE RIDES SHEX-011 EXPANDER CONE (12 DEG INCL) — SPEC 12.3 / 12.8.
4. TEETH: CASE HARDEN 55 HRC MIN, 0.020-0.030 CASE DEPTH; CORE 28-32 HRC.
5. SET AGAINST 9-5/8 40# CASING (ID 8.835 / DRIFT 8.679).
6. UPPER AND LOWER SEGMENTS IDENTICAL PROFILE; TOOTH RAKE OPPOSES LOAD DIRECTION.

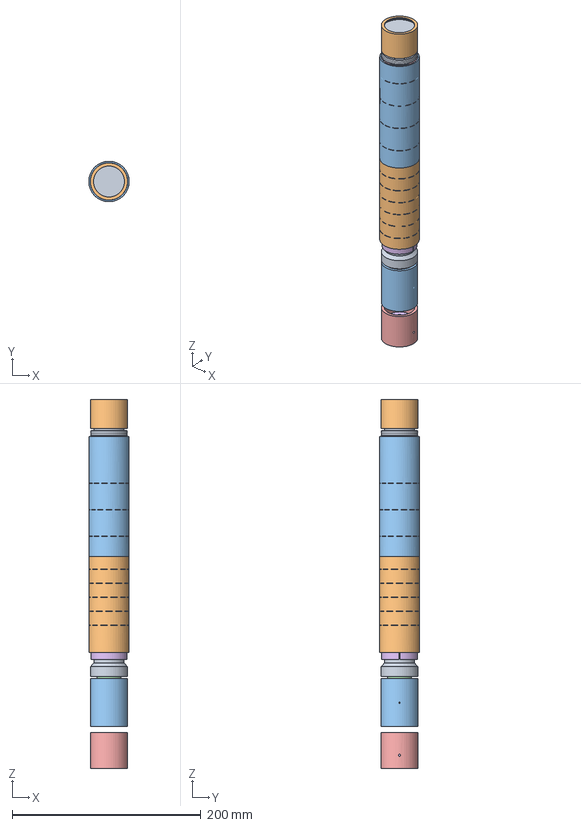
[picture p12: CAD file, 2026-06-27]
export/release/step/assemblies/SHEX-ACT-S12_RUN_IN.stp
42.8 x 42.9 x 391.2 mm

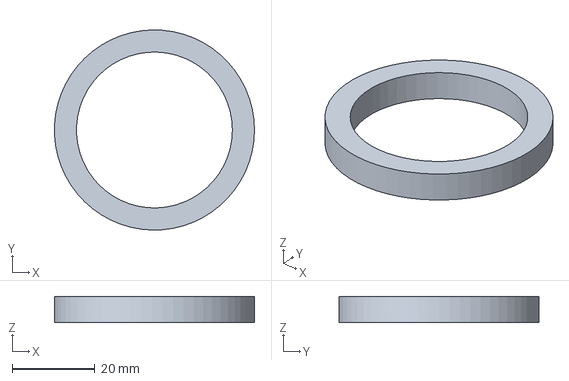
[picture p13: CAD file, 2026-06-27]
export/release/step/parts/ST-104_stroke_spacer.stp
48.2 x 48.2 x 6.35 mm

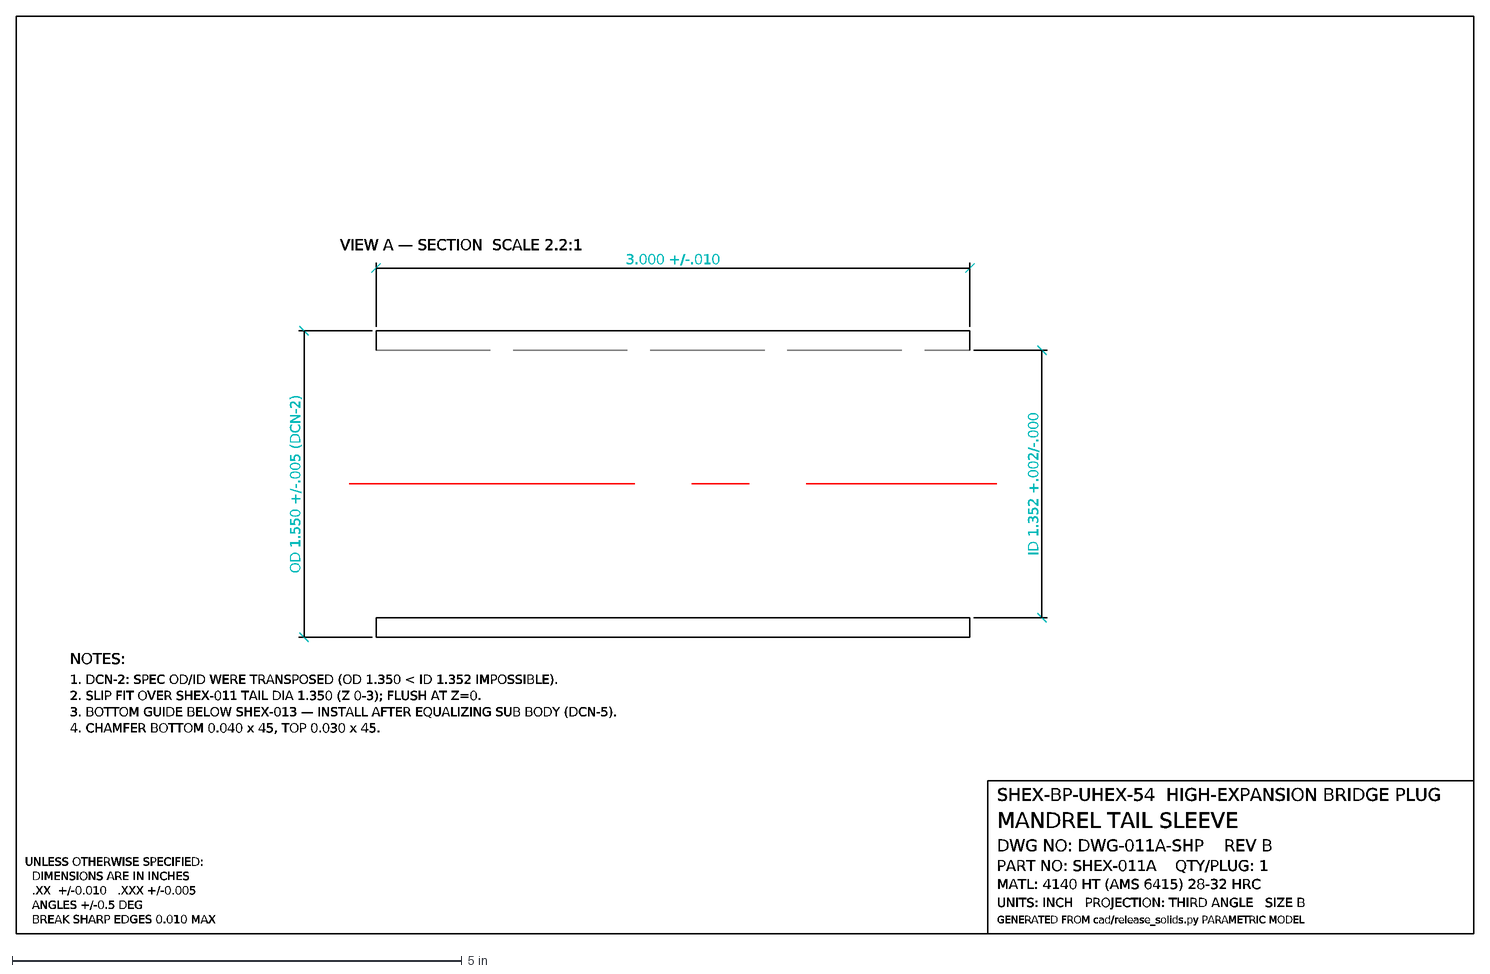
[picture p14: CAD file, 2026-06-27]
export/REVISIONS/Rev-B_DCN-12_CURRENT/drawings/dxf/DWG-011A-SHP_SHEX-011A_tail_sleeve.dxf
SHEX-BP-UHEX-54 HIGH-EXPANSION BRIDGE PLUG
MANDREL TAIL SLEEVE
DWG NO: DWG-011A-SHP REV B
PART NO: SHEX-011A QTY/PLUG: 1
MATL: 4140 HT (AMS 6415) 28-32 HRC
UNITS: INCH PROJECTION: THIRD ANGLE SIZE B
GENERATED FROM cad/release_solids.py PARAMETRIC MODEL
BREAK SHARP EDGES 0.010 MAX
ANGLES +/-0.5 DEG
.XX +/-0.010 .XXX +/-0.005
DIMENSIONS ARE IN INCHES
UNLESS OTHERWISE SPECIFIED:
VIEW A — SECTION SCALE 2.2:1
3.000 +/-.010
OD 1.550 +/-.005 (DCN-2)
ID 1.352 +.002/-.000
NOTES:
1. DCN-2: SPEC OD/ID WERE TRANSPOSED (OD 1.350 < ID 1.352 IMPOSSIBLE).
2. SLIP FIT OVER SHEX-011 TAIL DIA 1.350 (Z 0-3); FLUSH AT Z=0.
3. BOTTOM GUIDE BELOW SHEX-013 — INSTALL AFTER EQUALIZING SUB BODY (DCN-5).
4. CHAMFER BOTTOM 0.040 x 45, TOP 0.030 x 45.

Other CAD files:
export/REVISIONS/Rev-B_DCN-12_CURRENT/step/parts/SHEX-008_stage1_stent_runin.stp
export/stent/developed_dxf/SHEX-009_developed_RUNIN.dxf
export/ansys/step/iris_segment_production_mm.stp
cad/irisassy01.f3d
cad/irisassy3.f3d
cad/irisrep2.f3d
export/REVISIONS/Rev-A_DCN-01-11_PREVIOUS/drawings/dxf/ACT-DWG-014A_gland_ring.dxf
export/REVISIONS/Rev-A_DCN-01-11_PREVIOUS/drawings/dxf/ACT-DWG-014B_lock_ring.dxf
export/REVISIONS/Rev-A_DCN-01-11_PREVIOUS/drawings/dxf/ACT-DWG-014C_charge_sub.dxf
export/REVISIONS/Rev-A_DCN-01-11_PREVIOUS/drawings/dxf/ACT-DWG-015_belleville.dxf
export/REVISIONS/Rev-A_DCN-01-11_PREVIOUS/drawings/dxf/ACT-DWG-016_chamber_pilot.dxf
export/REVISIONS/Rev-A_DCN-01-11_PREVIOUS/drawings/dxf/DWG-001-SHP_SHEX-001_iris_segment.dxf
export/REVISIONS/Rev-A_DCN-01-11_PREVIOUS/drawings/dxf/DWG-002A-SHP_SHEX-002_helix_guide.dxf
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

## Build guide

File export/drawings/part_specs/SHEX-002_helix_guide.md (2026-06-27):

# SHEX-002 — Iris Helix Guide Insert — Shop Drawing Spec

**Drawing No:** DWG-002A-SHP  
**Part No:** SHEX-002  
**Qty:** 1 per plug  
**Material:** Inconel 718 (AMS 5662), solution + age per spec  
**Tier:** **MANUFACTURING** — fits inside **SHEX-010** bore (≤ **Ø1.560** OD)  
**STEP import:** None — model in Fusion  
**Module ref:** `SHEX-IRIS_STACK_INDEX.md`  
**Mates:** **SHEX-010** pocket **Z′ = 3.250 – 7.250**; **SHEX-001** followers; **SHEX-011** cams §12.5

---

## 1. Function

**Double-start helix** insert fixed in support sleeve. Converts mandrel **axial + rotation** (setting tool Phase 4) into **radial segment motion** via **SHEX-001** follower slots riding in helix grooves.

| Parameter | Value |
|---|---|
| **Lead** | **4.0 in** per full rotation |
| **Starts** | **2** (180° apart) |
| **Active axial length** | **4.0 in** |
| **Mandrel stroke** | **4.0 in** + **~2 rev** |

---

## 2. Envelope (shop)

| Feature | Dimension (in) | Tolerance | Notes |
|---|---|---|---|
| **OD** | **1.555** | +0.000 / −0.002 | Press/slip in **SHEX-010** pocket **Ø1.558** |
| **ID** | **Ø1.552** | +0.003 / −0.000 | Clears **Ø1.550** mandrel |
| **Length** | **4.000** | ±0.005 | |
| **Wall (nominal)** | **0.0015** | — | Thin ring — helix cut in ID |

**Install position (part Z′):** bottom @ **Z′ = 3.250**, top @ **Z′ = 7.250** (module local).

---

## 3. Helix grooves (2-start)

Cut on **inner diameter** — segment followers travel here.

| Feature | Dimension (in) | Tolerance | Notes |
|---|---|---|---|
| **Form** | Double-start helix | — | |
| **Lead** | **4.000** | ±0.010 | Axial per **360°** |
| **Groove width** | **0.125** | ±0.005 | |
| **Groove depth** | **0.080** | ±0.003 | Into wall from ID |
| **Starts** | **2** @ **180°** | — | |
| **Pitch** *(double-start)* | **2.000** axial / rev | — | 4.0 lead ÷ 2 starts |
| **Total rotation span** | **720°** | — | Over **4.0 in** length |
| **Root fillet** | **R0.015** min | — | EDM |

### 3.1 Groove centreline (module Z′, start @ 3.250)

| Start **Z′** | End **Z′** | Rotation |
|---|---|---|
| **3.250** | **7.250** | **2 rev** total |

---

## 4. Segment follower interface

Each **SHEX-001** segment carries a tab into groove:

| Feature | Dimension (in) | Notes |
|---|---|---|
| Follower width | **0.125** | Matches groove |
| Follower length | **0.625** | Per **SHEX-001** §4 |
| Radial clearance | **0.005** per side | In groove |

---

## 5. Retention

| Feature | Spec |
|---|---|
| Method | Split ring / pin / epoxy pocket per **SHEX-010** §4 |
| Anti-rotation | Pin **Ø0.062** through sleeve + insert, **1 place** |

---

## 6. Required drawing views (DWG-002A-SHP)

| View | Scale | Content |
|---|---|---|
| A | **2:1** | Half-section — ring **4.0 L** |
| B | **2:1** | Developed helix unwrap (one start) — **lead 4.0** |
| C | **4:1** | Groove cross-section |
| D | **1:1** | End view — **2 starts @ 180°** |

---

## 7. Dimension checklist

- [ ] OD **1.555**, ID **Ø1.552**, length **4.000**
- [ ] Helix lead **4.000**, **2-start**
- [ ] Groove **0.125 × 0.080**
- [ ] Install **Z′ = 3.250 – 7.250** *(reference dim on assy)*
- [ ] Material **Inconel 718**
- [ ] Part number **SHEX-002**

---

## 8. General notes

```
1. UNLESS OTHERWISE SPECIFIED, DIMENSIONS ARE IN INCHES.
2. MATERIAL: INCONEL 718 — AMS 5662.
3. MANUFACTURE: EDM OR 5-AXIS PREFERRED FOR HELIX GROOVES.
4. LEAD 4.000 IN VERIFIED WITH MANDREL CAMS (SHEX-011 §12.5).
5. FUNCTIONAL TEST IN SHEX-010 POCKET WITH 1× SHEX-001 + MANDREL.
6. NOT FOR SET OD 5.750 / 8.650 — RUN-IN MODULE ONLY.
```

---

## 9. Fusion workflow

1. Design **`05_SHEX-002_helix_guide`**.
2. Create base ring: **OD 1.555 × ID 1.552 × L 4.0**.
3. **Helix groove** toolpath or Coil path: **2 starts**, pitch **2.0 in/rev**, length **4.0**.
4. Validate with **SHEX-011** mandrel cams @ plug **Z = 19 – 23**.
5. Drawing **DWG-002A-SHP** → `shop_pdf/`.

**Reference schematic:** `dxf/DWG-002_iris_module_assy.dxf` VIEW 3.

---

*Rev A — helix insert for run-in iris module.*

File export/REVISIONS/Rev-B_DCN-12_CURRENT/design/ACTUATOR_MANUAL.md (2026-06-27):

# SHEX-BP-UHEX-54 Stage 1/2 Internal Actuators

## Engineering, Manufacturing & Operations Manual

| | |
|---|---|
| Document | SHEX-MAN-003 **Rev B** |
| Scope | the internal "first stroke" — radial expansion Ø1.688 → Ø5.750 |
| Parts | SHEX-014 (stage-1 bladder), SHEX-015 (stage-2 bladder + hold), SHEX-016 (charge/EQ pilot), **SHEX-017 (sequence/initiation sub, DCN-12)** |
| Geometry authority | `cad/actuator_solids.py` → `../step/parts/SHEX-01*.stp` |
| Sizing authority | `export/analysis/actuator_design.py`, **`trigger_design.py`** (+ `.json`) |
| Drawings | ACT-DWG-014A/014B/014C/015/016/**017** in `../drawings/` |
| Companion docs | `MANUAL.md` (plug), `SETTING_TOOL_MANUAL.md` (kit), **`FIRST_STROKE_TRIGGER.md` (SHEX-EM-001)** |

> **Rev B (DCN-12).** The first-stroke **trigger and equalizing-sleeve
> interlock** are now engineered, not narrated. A passive hydrostatic burst
> disk has no position control (it fires during run-in — proven in
> `trigger_design.py` §1), so it is replaced by **commanded initiation +
> completion-gated sequencing** via the new **SHEX-017** sub. See the new
> [§1.4–1.6](#part-1--engineering-design) and [Part 5 DCN-12](#part-5--design-change-notices).

**Contents**

- [Part 0 — Where this fits](#part-0--where-this-fits)
- [Part 1 — Engineering design](#part-1--engineering-design)
- [Part 2 — Sizing & calculations](#part-2--sizing--calculations)
- [Part 3 — Manufacturing guide](#part-3--manufacturing-guide)
- [Part 4 — Assembly, arming & operation](#part-4--assembly-arming--operation)
- [Part 5 — Design Change Notices (DCN-10/11)](#part-5--design-change-notices)
- [Part 6 — Assumptions & open items](#part-6--assumptions--open-items)
- [Appendix A — File index](#appendix-a--file-index)

---

# Part 0 — Where this fits

The plug is a **two-actuator machine**. The setting-tool manual covers the
**secondary stroke** (the 10-in axial stroke from a Baker #20 tool that drives
stage-3 iris, seals and slips). This manual covers the **first stroke**: the
two internal radial expansions that open the plug from its Ø1.688 run-in
envelope to Ø5.750 **before the setting tool ever strokes.**

| | First stroke (this manual) | Secondary stroke (setting-tool manual) |
|---|---|---|
| Driver | internal, pressure-driven bladders | external setting tool, 10-in axial |
| Stages | 1 (→Ø3.375) and 2 (→Ø5.750) | 3 iris + 4 seals + slips |
| Energy | wellbore hydrostatic / applied CT pressure | gas charge (e-line) or CT pressure |

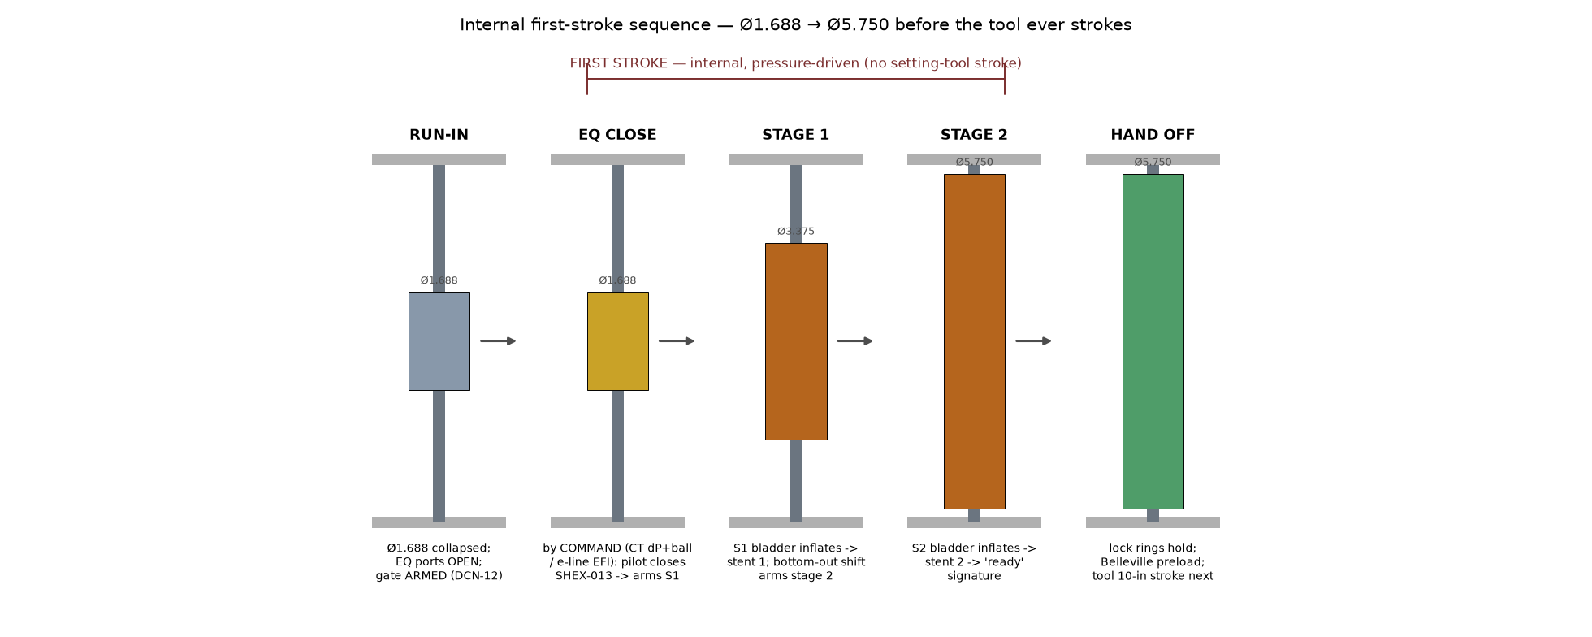
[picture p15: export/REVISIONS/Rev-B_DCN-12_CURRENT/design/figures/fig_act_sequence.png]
Internal first-stroke sequence


These actuators were referenced in the original concept (`SHEX-014` bladder,
`SHEX-015` Belleville) but never engineered or modelled. This release designs,
sizes, models and draws them — and corrects two inherited assumptions (DCN-10,
DCN-11).

---

# Part 1 — Engineering design

## 1.1 The annulus is the whole problem

Through the stage-1 (plug Z 9.5–13.5) and stage-2 (Z 13.5–18.5) zones the inner
mandrel is necked to **Ø1.270** (the DCN-1 helix neck). The laser-cut mesh
stent sleeves (SHEX-008/009) have **ID 1.562 / OD 1.688**. So the actuators
must live in a **0.146-in radial annulus** (0.292 diametral). Every design
choice flows from this.

## 1.2 Why both stages are inflatable bladders (DCN-11)

The original concept used a bladder for stage 1 and a **Belleville-driven
swage/wedge** for stage 2. That cannot work here:

- To back the mesh at its **final** Ø5.624 (under-stent), a rigid swage/cone
  must reach radius **2.812 in**.
- But at run-in every part must be **≤ stent ID 1.562** (radius 0.781).
- A rigid body starting at r 0.781 cannot grow to r 2.812 — and a Belleville
  stack that fits a 0.146-in annulus makes only ~250 lbf/washer, nowhere near
  the ~10–25 klbf radial demand.

Only an element that **folds small and inflates large** can span 1.27 → 5.62.

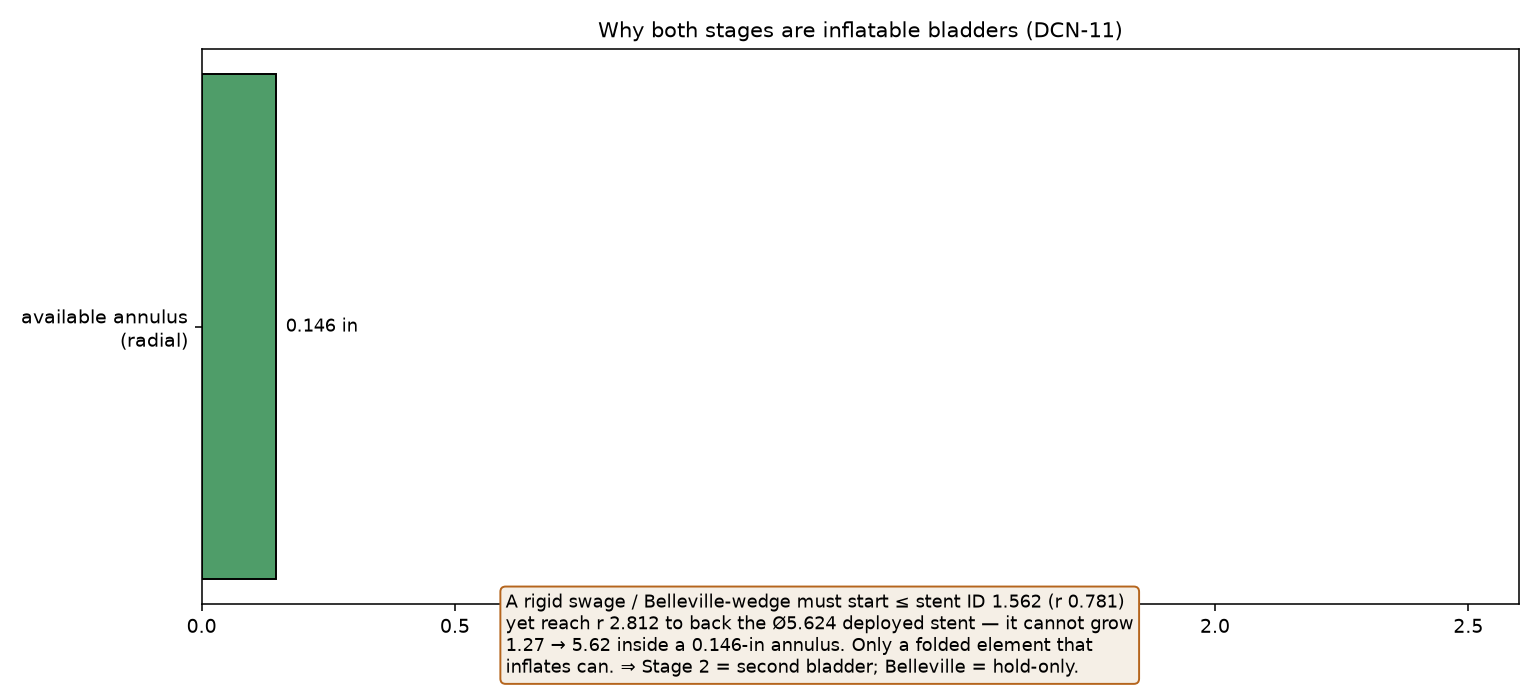
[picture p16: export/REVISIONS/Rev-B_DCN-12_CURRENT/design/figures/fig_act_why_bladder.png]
Why bladders


**Decision (DCN-11):** stage 2 is a **second inflatable bladder**, sequenced
after stage 1. The Belleville stack is retained **only** as a hold-open /
anti-recoil preload.

## 1.3 How a stage deploys

Each stage is a balloon-expandable mesh, scaled up from vascular-stent
practice:

1. A **reinforced HNBR bladder** (SHEX-014 / SHEX-015) sits folded in the
   annulus, sealed to the mandrel neck at both ends by **gland/swage rings**
   (SHEX-014A).
2. A **burst-disk charge sub** (SHEX-014C) admits a pressure source into the
   bladder bore.
3. The bladder inflates radially and plastically opens the laser-cut mesh
   stent to its deployed diameter.
4. A **body-lock ratchet ring** (SHEX-014B / 015D) walks up a mandrel ratchet
   band and **holds the stent open** after pressure bleeds off; the Belleville
   stack (SHEX-015B) maintains light axial preload against recoil.

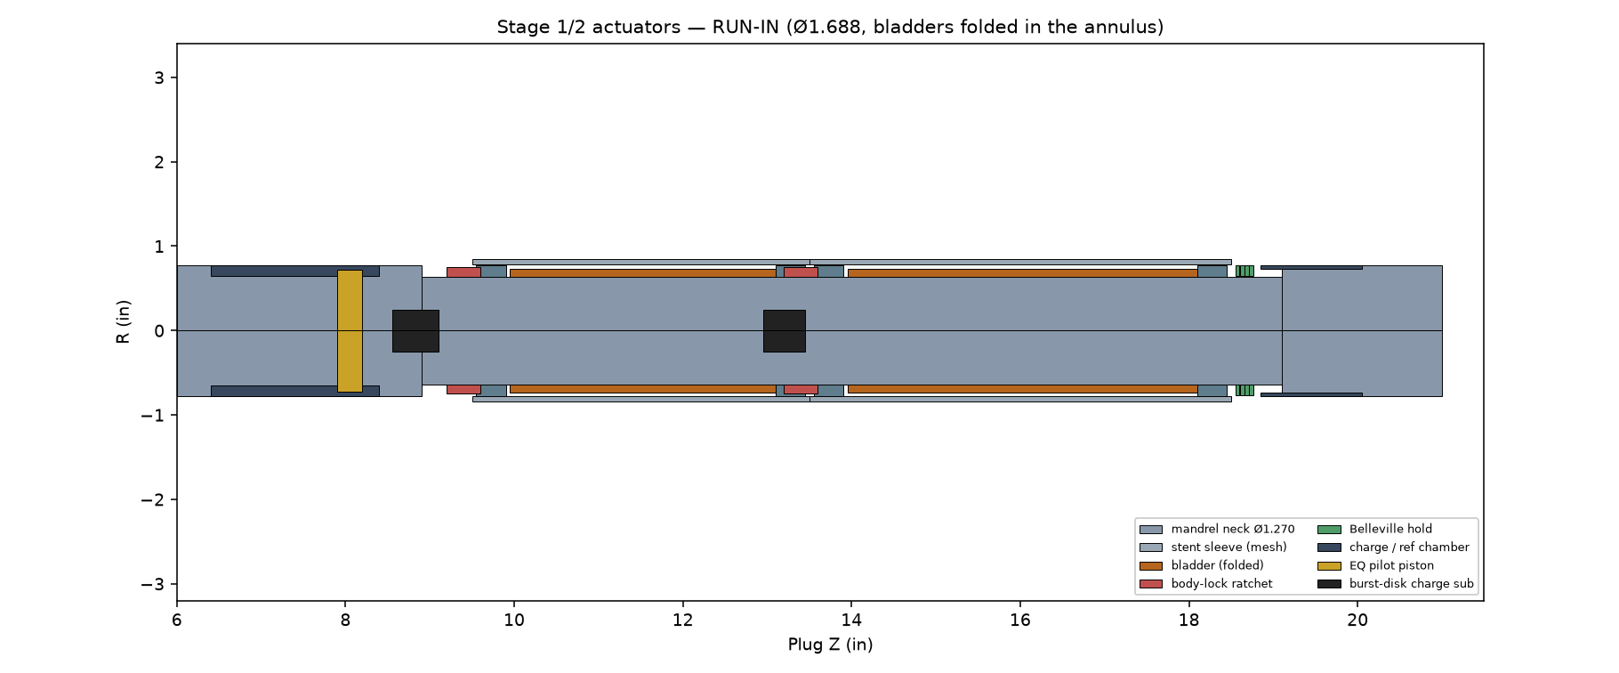
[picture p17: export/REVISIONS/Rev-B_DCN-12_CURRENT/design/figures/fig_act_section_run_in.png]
Run-in

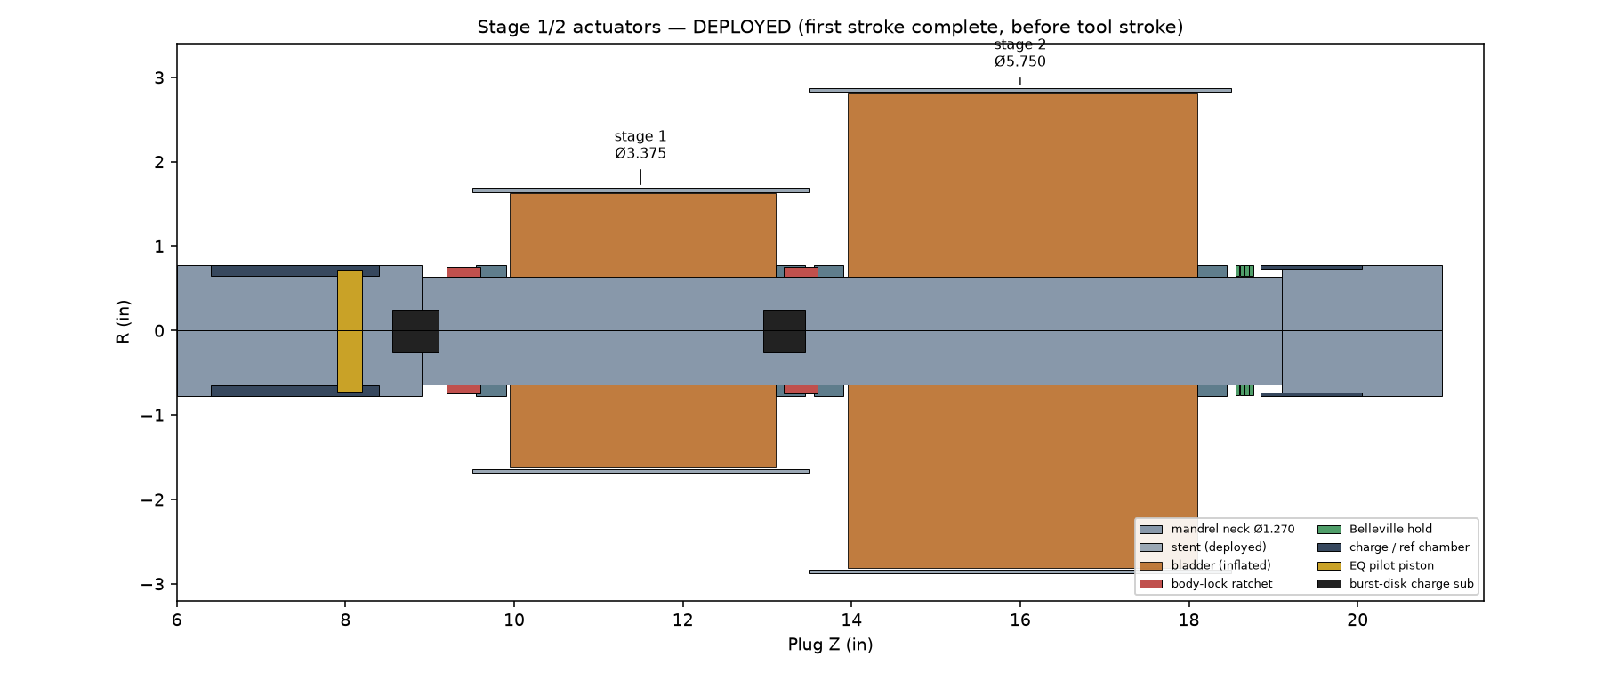
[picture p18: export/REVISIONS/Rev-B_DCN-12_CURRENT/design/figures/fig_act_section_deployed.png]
Deployed


## 1.4 Energy source — the well does the work

The bladders are **not** driven by a tiny self-contained chamber (which could
never store the ~1898 cc / energy in this annulus). They are driven by the
**well**, *gated* by the SHEX-017 sub:

- **Coiled tubing:** applied **pump pressure** down the CT — fully controlled,
  the preferred path.
- **Electric wireline:** **wellbore hydrostatic** pressure, admitted when an
  EFI gate is fired (§1.5). At 3000 ft / 9 ppg the hydrostatic is ~1400 psi; at
  8000 ft ~3744 psi — both exceed the deploy demand (Part 2). A small
  pyrotechnic gas generator is the documented boost for shallow/low-hydrostatic
  sets (hydrostatic < p1 ≈ 941 psi, i.e. below ~2000 ft).

## 1.5 Trigger & interlock — DCN-12 (this is what makes the first stroke *real*)

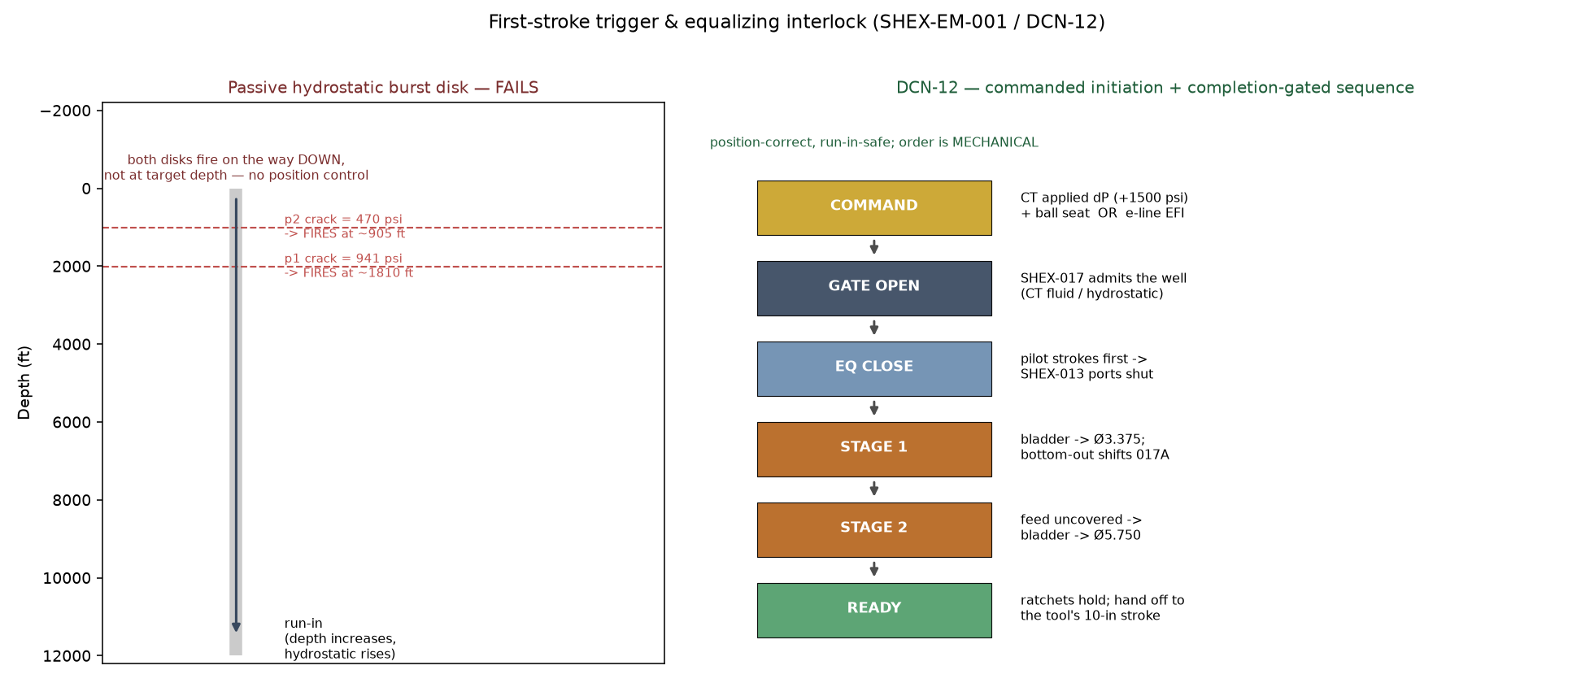
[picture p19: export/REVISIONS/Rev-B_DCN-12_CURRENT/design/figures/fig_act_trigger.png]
Trigger / interlock


The inherited concept (a burst disk referenced to a sealed chamber, firing at
p1 < p2 with a 30 s orifice) **cannot work**: a disk referenced to absolute
hydrostatic fires at the depth where hydrostatic equals its crack pressure —
**on the way down, not at target depth.** There is no single pressure that both
survives run-in to a deep target and fires only at depth (proven in
`trigger_design.py` §1; full reasoning in **SHEX-EM-001**). So **DCN-12**
separates the three jobs that concept conflated:

| Job | DCN-12 solution |
|---|---|
| **Energy / volume** | the well (CT fluid or hydrostatic), gated by SHEX-017 |
| **Initiation** | a position-correct **command** — CT applied differential (+~1500 psi over annulus) + **ball seat**, or e-line **EFI gate** |
| **Sequencing** | **completion-gated** — each stent's bottom-out pressure climb shifts a shear-pinned arming sleeve that uncovers the next stage's feed |

**The SHEX-017 sequence / initiation sub** houses the gate, the ball seat /
reference piston (CT) and EFI port (e-line), the **stage1→2 arming sleeve**
(SHEX-017A), the metering orifice (plateau damping only) and the **feed
manifold** to both bladder lines.

## 1.6 Sequence (single command, mechanically ordered)

Sequence

1. **Arm (surface):** ball out / EFI continuity OK; EQ ports OPEN; gate armed.
2. **Initiate (at depth, by COMMAND):** CT applied dP (+~1500 psi) **or** e-line
   EFI fire → opens the SHEX-017 gate to the manifold.
3. **EQ close:** the **pilot piston** (SHEX-016A) strokes **first** (lowest
   preload, shortest travel) → shifts the SHEX-013 sleeve **closed** → its
   end-of-stroke **uncovers the stage-1 feed**. EQ-before-S1 is now mechanical.
4. **Stage 1:** bladder 1 inflates → stent 1 → Ø3.375. At its **hard stop** the
   pressure climbs from the deploy plateau and **shears/shifts SHEX-017A**,
   uncovering the stage-2 feed.
5. **Stage 2:** bladder 2 inflates → stent 2 → Ø5.750 → "ready" signature.
6. **Hand off:** body-lock ratchets hold both stages; the plug is at Ø5.750 and
   ready for the setting tool's secondary stroke.

Order is a **physical guarantee** — independent of depth, temperature and pump
rate — rather than a set of absolute pressure thresholds. No downhole
electronics are required beyond the e-line EFI initiator (which the E-4 setting
tool already carries).

---

# Part 2 — Sizing & calculations

First-order hand calcs (authority `actuator_design.py`). **Not** a substitute
for FEA + full-scale test (Part 6).

## 2.1 Expansion mechanics (ductile mesh, thin-wall hoop p = σ·t_eff/r)

| Stage | OD | ΔR/side | deploy p (worst case) | hold p | radial force at final OD |
|---|---|---|---|---|---|
| 1 | 1.688 → 3.375 | 0.844 | ~941 psi | ~470 psi | ~19,950 lbf |
| 2 | 3.375 → 5.750 | 1.188 | ~470 psi | ~276 psi | ~24,938 lbf |

σy = 30 ksi (annealed 316L, per DCN-10), ligament fraction 0.42, t 0.063.

## 2.2 Bladder sizing

| | Stage 1 | Stage 2 |
|---|---|---|
| Run-in (folded) OD | ~1.462 in | ~1.462 in |
| Deployed OD (to stent ID) | ~3.249 in | ~5.624 in |
| Inflation volume ΔV | ~26 in³ (433 cc) | ~116 in³ (1898 cc) |
| Deploy pressure | ~941 psi | ~470 psi |
| Design rating | 2500 psi (burst ≥ 3×) | 2500 psi |

## 2.3 Pressure budget vs available energy

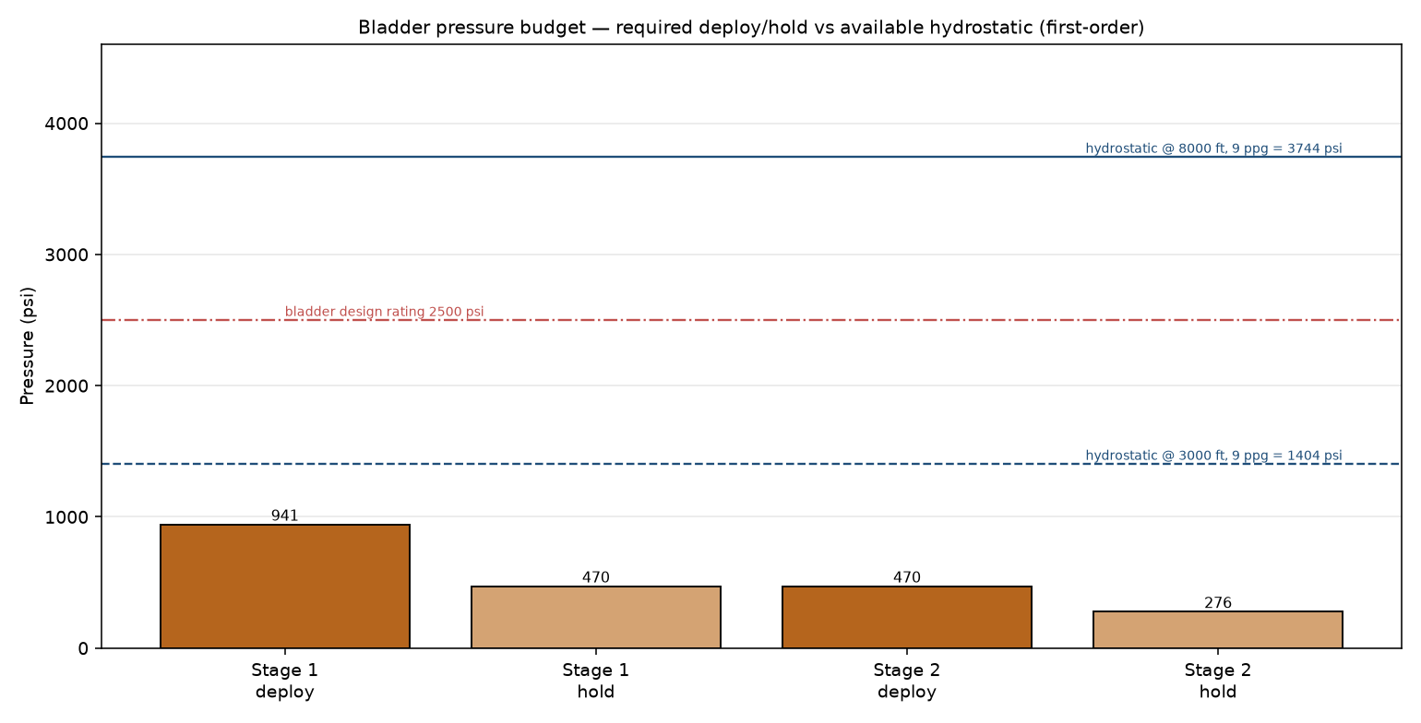
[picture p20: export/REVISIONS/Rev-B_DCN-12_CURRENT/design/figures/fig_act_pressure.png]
Pressure budget


The required deploy/hold pressures sit **below** both the bladder design rating
and the hydrostatic available even at 3000 ft — i.e., the well has ample energy
to deploy both stages. Stage 2 needs *less* pressure than stage 1 (larger
radius), which is convenient for the p1 < p2 sequencing.

## 2.4 Belleville hold stack

Annulus-limited washer (OD 1.540 / ID 1.290) ≈ 250 lbf each; **4 in series**
give ~200–300 lbf of anti-recoil preload over ~0.2 in — adequate as a *hold*,
confirming it cannot be the radial *driver*.

---

# Part 3 — Manufacturing guide

## 3.1 General

- Inch dimensions; tolerances per drawing (.XX ±0.010, .XXX ±0.005 unless noted).
- MPI all metal load parts after machining.
- Etch part no + heat/lot in a non-functional surface.

## 3.2 Per-part routes

| Part | Drawing | Material | Key features |
|---|---|---|---|
| SHEX-014 / 015 bladder | (elastomer spec) | HNBR + ply reinforcement | folded run-in OD ~1.46; deployed 3.25 / 5.62; 2500 psi rating, burst ≥3× |
| SHEX-014A gland / swage ring | ACT-DWG-014A | 17-4 PH H1075 | OD 1.550 / ID 1.270 × 0.350; OD crimp groove; bore concentric 0.002 FIM (4/plug) |
| SHEX-014B / 015D lock ring | ACT-DWG-014B | 17-4 PH H1075 | OD 1.500 / ID 1.270 × 0.400; 3 internal saw-teeth; 0.040 axial split; teeth harder than mandrel band |
| SHEX-014C / 015E charge sub | ACT-DWG-014C | 4140 HT + COTS burst disk | OD 0.500 × 0.550; disk counterbore 0.300; passage 0.125; stage-2 adds metering orifice |
| SHEX-015B Belleville | ACT-DWG-015 | Inconel 718 | OD 1.540 / ID 1.290; free height 0.100; stock 0.050; 4 in series |
| SHEX-015C Belleville housing | ACT-DWG-015 | 4140 HT | OD 1.550 / ID 1.290 × 1.200; counterbore 1.460 × 0.95 |
| SHEX-016 charge chamber | ACT-DWG-016 | 4140 HT | OD 1.550 / ID 1.300 × 2.000; 2 pilot ports 0.062 |
| SHEX-016A pilot piston | ACT-DWG-016 | 17-4 PH H1075 | seal land OD 1.450; stem 1.000; nose 0.700; 2 O-ring grooves |
| **SHEX-017 sequence sub** | ACT-DWG-017 | 4140 HT | OD 1.550 / bore 1.300 × 1.50; EFI/pilot port 0.200; 2× manifold feed 0.094; metering orifice 0.040; 2 ref-piston seal lands |
| **SHEX-017A arming sleeve** | ACT-DWG-017 | 17-4 PH H1075 | OD 1.290 / ID 1.050 × 0.60; feed port 0.094; 0.093 shear-pin hole (calibrated ~1720 psi) |
| **SHEX-017B reference piston** | ACT-DWG-017 | 17-4 PH H1075 | seal land OD 1.290; stem 1.000; Ø0.50 flow bore + tapered ball seat; 2 O-ring grooves |

## 3.3 Bladder fabrication notes

- Build like an inflatable-packer element: HNBR over a braided/woven ply
  carcass; ends vulcanised to steel inserts that the gland rings swage.
- Fold (not roll) at run-in so it opens evenly; protect during stent crimp.
- Proof each bladder to design rating; burst-sample per lot.

## 3.4 Stent material (DCN-10)

The stent sleeves SHEX-008/009 must be a **ductile, plastically-expandable
alloy** (annealed 316L or a Ni alloy) — **not** 17-4 PH H900, which is too
strong/brittle to hinge ~2× without cracking. Update the SHEX-008/009 shop
sheets accordingly.

---

# Part 4 — Assembly, arming & operation

## 4.1 Sub-assembly (shop)

1. Slip the **lower gland ring** (SHEX-014A) onto the mandrel neck at the stage
   datum; swage the **lower bladder end** into its crimp groove.
2. Fold the bladder over the neck; swage the **upper bladder end** into the
   **upper gland ring**; lock axially.
3. Install the **body-lock ratchet ring** below each stage over the mandrel
   ratchet band (one-way orientation — verify it walks the correct way).
4. Crimp the **laser-cut mesh stent** (SHEX-008/009) over the folded bladder to
   the Ø1.688 run-in envelope.
5. Stage 2 only: stack **4× Belleville** (SHEX-015B) in the **housing**
   (SHEX-015C), shim to preload, install above the stage.
6. Install the **SHEX-017 sequence sub** with its **reference piston**
   (SHEX-017B) and the **stage1→2 arming sleeve** (SHEX-017A, calibrated shear
   pin); land the **charge subs** (SHEX-014C/015E) as the manifold feed ports.
7. Install the **charge chamber** (SHEX-016) and **pilot piston** (SHEX-016A)
   below stage 1, tied to the SHEX-013 equalizing sleeve.

## 4.2 Arming (surface)

- **CT:** confirm the ball/dart and seat; pressure-test the gate below crack.
- **E-line:** install + continuity-check the **EFI initiator**; reference the
  SHEX-016 chamber (atmospheric or N₂ as specified).
- Confirm EQ ports OPEN; arming sleeve shear pin per spec; Belleville preload
  set. Record initiator lot / shear-pin calibration on the run ticket.

## 4.3 At depth — first stroke (DCN-12)

| Step | Coiled tubing | Electric wireline |
|---|---|---|
| Position | tag / space out | correlate CCL |
| **Initiate** | **drop ball, pump to hydrostatic + ~1500 psi** → opens gate | **fire EFI** → opens gate (hydrostatic then fills) |
| EQ close | gate pressure strokes pilot **first** → SHEX-013 closed → arms stage 1 | same (mechanical, gate-driven) |
| Stage 1 | bladder 1 → Ø3.375; **bottom-out shifts SHEX-017A** → arms stage 2 | same |
| Stage 2 | feed uncovered → bladder 2 → Ø5.750 | same |
| Confirm | pressure signature (gate / S1 plateau / S2 plateau) | time-tagged after fire; optional mandrel gauge |

Initiation is **position-correct** (you do it at depth, by command) and
**run-in-safe** (a ball-armed differential or an electrical signal — never bare
hydrostatic). Then proceed to the **secondary (tool) stroke** per
`SETTING_TOOL_MANUAL.md`.

## 4.4 Fail-safe states

| State reached | Plug condition | Recovery / next |
|---|---|---|
| Gate never opened | collapsed Ø1.688 | normal POOH — nothing fired |
| Gate open, EQ closed only | Ø1.688, ports shut | pull to re-open EQ via shift profile; fish on mandrel |
| Stage 1 only | Ø3.375, not anchored | recoverable on the mandrel; EQ re-opens on pull |
| Stages 1+2 complete | Ø5.750, locked open | proceed to the secondary (tool) stroke |
| Full set | Ø8.65 / seals / slips | tool shears free; plug holds |

## 4.5 Retrieval interaction

On retrieval the equalizing sub re-opens to balance pressure; the deployed
stents must collapse back onto the mandrel. A **shift-to-release profile** on
the mandrel (pulled by the fishing tool) is intended to release the one-way
body-lock rings — the detailed re-collapse kinematics remain an open item
(Part 6).

---

# Part 5 — Design Change Notices

- **DCN-10 — Stent material.** SHEX-008/009 re-specified from 17-4 PH H900 to a
  **ductile expandable alloy** (annealed 316L or Ni alloy). A balloon/pressure-
  expandable mesh must plastically hinge ~2×; H900 would crack. Affects the
  SHEX-008/009 shop sheets and any FEA material model.
- **DCN-11 — Stage-2 prime mover.** Changed from a Belleville/swage **wedge** to
  a **second inflatable bladder**. A rigid expander starting ≤ stent ID 1.562
  cannot grow to back the Ø5.624 deployed stent in a 0.146-in annulus
  (geometric impossibility), and an annulus-fit Belleville stack is ~2 orders
  of magnitude short on force. The Belleville stack is retained **only** as a
  hold-open / anti-recoil preload (SHEX-015B).
- **DCN-12 — First-stroke initiation & sequencing.** Replaced the passive
  hydrostatic-referenced burst-disk trigger (p1<p2 + time orifice), which has
  **no position control and fires during run-in** (proven, `trigger_design.py`
  §1), with a **commanded-initiation, completion-sequenced** architecture:
  (a) energy from the well; (b) initiation by **CT applied differential + ball
  seat** *or* **e-line EFI gate**; (c) **completion-gated** sequencing where each
  stent's bottom-out pressure shifts an arming sleeve that enables the next
  stage, with the **EQ pilot interlocked to close first**. Adds sub **SHEX-017**
  (+ 017A arming sleeve, 017B reference piston); re-tasks SHEX-013/014C/015E/016A;
  defines fail-safe states (§4.4). Full rationale: **SHEX-EM-001**
  (`export/analysis/FIRST_STROKE_TRIGGER.md`).

---

# Part 6 — Assumptions & open items

## 6.1 Assumptions

1. **The well supplies the deploy energy** (applied CT pressure or hydrostatic).
   Genuinely shallow/low-hydrostatic sets need the gas-generator option.
2. **First-order mechanics only.** Deploy/hold pressures and forces are thin-
   wall hoop estimates with an assumed ligament fraction — directional, not
   qualified.
3. **The mesh holds its own shape once expanded** (like a vascular stent); the
   lock ring + Belleville are anti-recoil backups, not primary structure.
4. **Completion-gated sequencing** (DCN-12) — the stent bottom-out pressure
   climb reliably shifts the SHEX-017A arming sleeve across temperature — is the
   key assumption to validate by test (replaces the old p1<p2+orifice assumption).

## 6.2 Open items (carried in `FORWARD_PLAN.md`)

- **FEA** of mesh plastic expansion per stage (pressure, strain, fatigue, and
  the post-expansion hoop stiffness that resists recoil).
- **Full-scale deploy test** of bladder + stent in a representative annulus,
  **including the DCN-12 completion-gating pressure signature**.
- **EFI / gas-generator selection + qualification** (e-line) and the
  **ball-seat / CT-pressure interface** to the specific Model J tool.
- **Arming-sleeve + shear-pin calibration** (SHEX-017A) across temperature;
  metering-orifice (plateau-damping) sizing.
- **Body-lock ratchet** load rating **and retrieval re-collapse kinematics**
  (shift-to-release profile, §4.5).
- Confirm the **mandrel charge-port, manifold drillings and ratchet-band**
  features get added to the SHEX-011 mandrel drawing (referenced, not yet cut).

---

# Appendix A — File index

| Content | Path |
|---|---|
| This manual | `export/release/manual/ACTUATOR_MANUAL.md` |
| **Trigger memo (DCN-12)** | `export/analysis/FIRST_STROKE_TRIGGER.md` (SHEX-EM-001) |
| Figures (source) | `export/release/manual/figures_actuators.py` |
| Engineering analysis | `export/analysis/actuator_design.py`, **`trigger_design.py`** (+ `.json`) |
| Geometry (authority) | `cad/actuator_solids.py`, `generate_actuators.py` |
| STEP parts | `export/release/step/parts/SHEX-014*/015*/016*/**017***.stp` |
| Sub-assemblies | `export/release/step/assemblies/SHEX-ACT-S12_{RUN_IN,DEPLOYED}.stp` |
| Drawings | `export/release/drawings/{dxf,pdf}/ACT-DWG-014A/014B/014C/015/016/**017***` |
| Full tool (Rev B) | `export/full_tool/` (regenerated with SHEX-017) |
| Manifest | `export/release/manifest_actuators.json` |
| 3D previews | `export/release/png/SHEX-ACT-S12_*` |
| Verify script | `export/release/verify_actuators.py` |
| Working log / plan | `WORKING_LOG.md`, `FORWARD_PLAN.md` |

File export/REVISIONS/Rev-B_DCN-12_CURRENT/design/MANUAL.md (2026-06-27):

# SHEX-BP-UHEX-54 Ultra-High-Expansion Bridge Plug

## Engineering, Manufacturing & Assembly Manual

| | |
|---|---|
| Document | SHEX-MAN-001 Rev A |
| Tool | SHEX-BP-UHEX-54 thru-tubing retrievable bridge plug |
| Run-in OD / OAL | Ø1.688 in / 57.0 in (DCN-4) |
| Set casing | 9-5/8 in 40 lb/ft (ID 8.835, drift 8.679) |
| Rating target | 3,000–5,000 psi differential (FEA pending — §1.10) |
| Geometry authority | `cad/release_solids.py` → STEP files in `../step/` |
| Drawing set | 14 sheets in `../drawings/pdf/` (DXF in `../drawings/dxf/`) |

**Contents**

- [Part 1 — Engineering design](#part-1--engineering-design)
- [Part 2 — Manufacturing guide](#part-2--manufacturing-guide)
- [Part 3 — Assembly guide](#part-3--assembly-guide)
- [Appendix A — File index](#appendix-a--file-index)

---

# Part 1 — Engineering design

## 1.1 What this tool is

SHEX-BP-UHEX-54 is a thru-tubing bridge plug that runs at Ø1.688 in — small
enough to pass 2-3/8 in tubing — and sets in 9-5/8 in 40# casing, an
expansion ratio of **5.2 : 1** (8.835 / 1.688). No conventional plug
approaches this ratio; the design borrows the staged-expansion architecture
of vascular stents and catheter-deployed implants, scaled to oilfield loads
and re-implemented in machinable alloys.

The tool sets with a single axial stroke of the inner mandrel (+11.0 in,
≤55 klbf from the SHEX-ST-54 setting tool). Everything else — slips, stent
shells, iris segments, seal energization, metal-to-metal backup, equalizing
valve — is driven from that one stroke through cams, tapers and a helical
lead screw machined on the mandrel.

Run-in (collapsed) general arrangement:

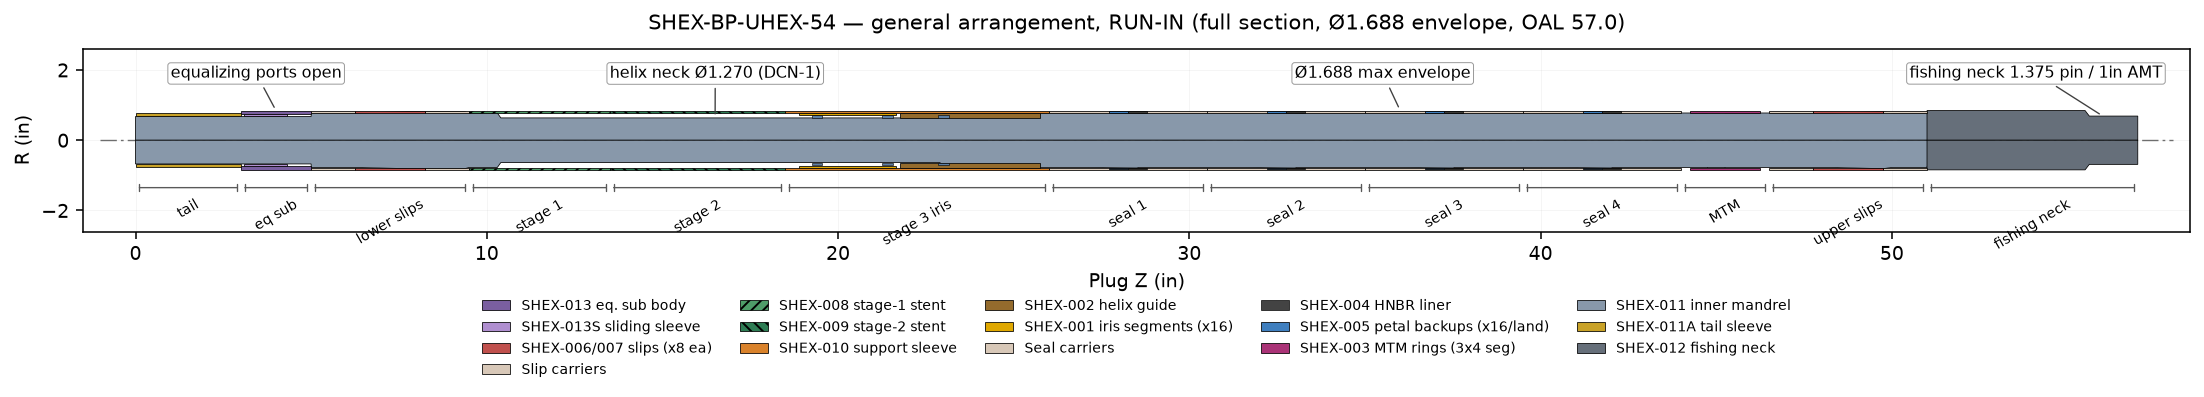
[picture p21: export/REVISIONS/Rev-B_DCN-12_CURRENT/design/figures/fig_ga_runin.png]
Run-in GA


Set (expanded) general arrangement in casing:

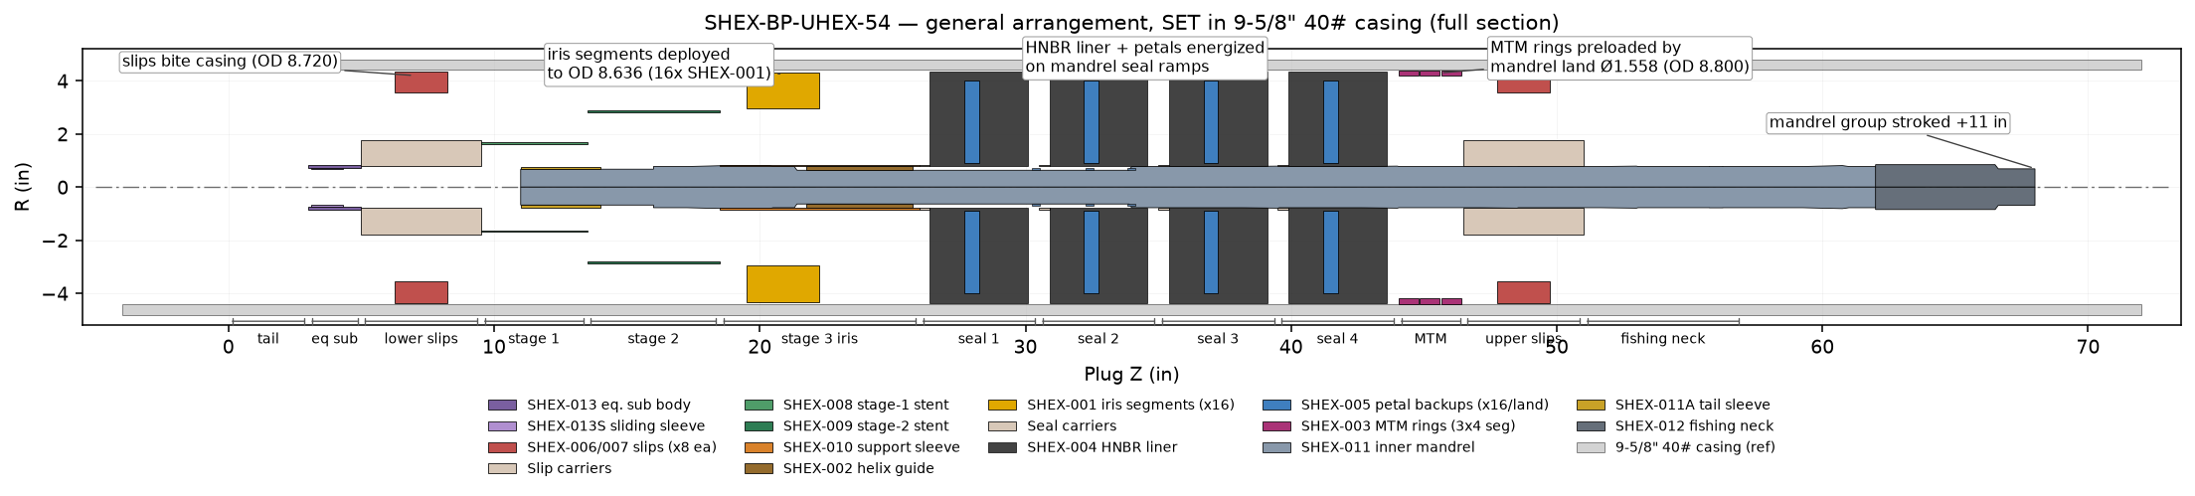
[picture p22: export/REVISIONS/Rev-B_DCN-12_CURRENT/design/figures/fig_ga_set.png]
Set GA


3D views of the released geometry: [run-in render](../png/SHEX-BP-UHEX-54_RUN-IN.png),
[set render](../png/SHEX-BP-UHEX-54_SET.png),
[set half-section](../png/SHEX-BP-UHEX-54_SET_section.png).

## 1.2 Module map

The plug is a stack of functional modules on a common mandrel. Plug Z is
measured from the bottom of the tool, increasing uphole.

| Plug Z (in) | Module | Key parts |
|---|---|---|
| 0.0 – 3.0 | Mandrel tail / bottom guide | SHEX-011 tail, SHEX-011A sleeve |
| 3.0 – 5.0 | Bottom equalizing sub | SHEX-013 body, SHEX-013S sleeve |
| 5.0 – 9.5 | Lower slips | 8× SHEX-007 + carrier |
| 9.5 – 13.5 | Stage-1 stent | SHEX-008 |
| 13.5 – 18.5 | Stage-2 stent | SHEX-009 |
| 18.5 – 26.0 | Stage-3 iris | SHEX-010 sleeve, SHEX-002 guide, 16× SHEX-001 |
| 26.0 – 44.0 | Seal lands ×4 (4.5 in each) | SHEX-004 liner + 16× SHEX-005 petals each |
| 44.0 – 46.5 | Upper MTM backup | 12× SHEX-003 (3 rings × 4) |
| 46.5 – 51.0 | Upper slips | 8× SHEX-006 + carrier |
| 51.0 – 57.0 | Fishing neck / top sub | SHEX-012 |

## 1.3 The mandrel is the machine

SHEX-011 is a solid 17-4 PH bar, finished length 52.500 in, that carries
every actuation feature as an OD step, taper, rib or land. There is no
through-bore — pressure integrity below the seals does not depend on an
internal plug.

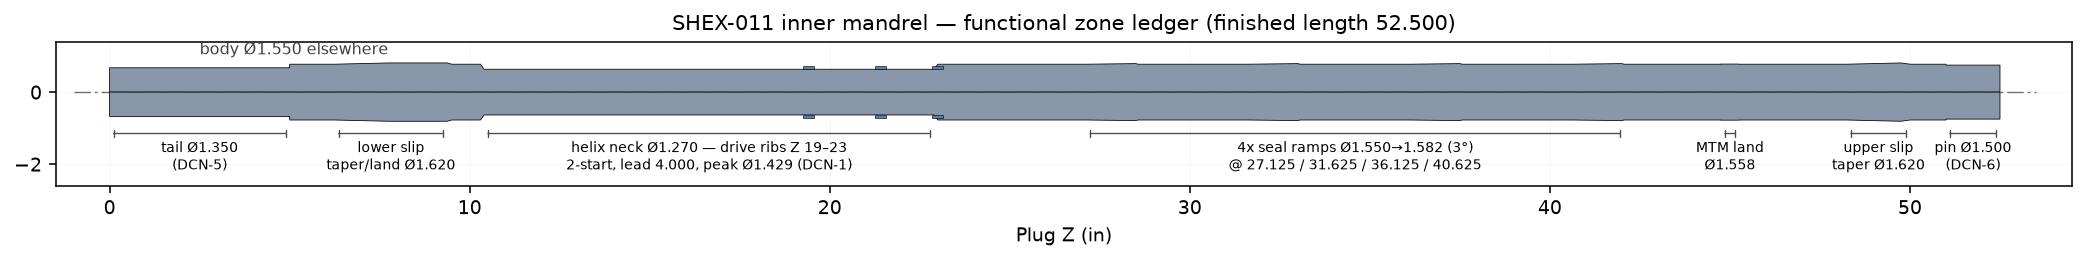
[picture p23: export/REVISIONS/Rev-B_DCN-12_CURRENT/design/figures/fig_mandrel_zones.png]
Mandrel zones


Functional zones (bottom → top):

| Z (in) | Feature | Drives |
|---|---|---|
| 0 – 5.0 | Tail Ø1.350 (DCN-5) | Equalizing sleeve + bottom guide |
| 6.25 – 9.5 | Taper Ø1.550→1.620 + land | Lower slip expansion (12° incl) |
| 10.4 – 22.9 | Helix neck Ø1.270 (DCN-1) | Clearance for iris drive |
| 19.0 – 23.0 | 2-start drive ribs, lead 4.000, peak Ø1.429 | Iris rotation/expansion |
| 27.125 – 42.0 | 4× seal ramps Ø1.550→1.582 (3°) | HNBR seal energization |
| 44.75 – 45.25 | MTM land Ø1.558 | MTM ring preload |
| 48.25 – 50.0 | Taper Ø1.550→1.620 | Upper slip expansion |
| 51.0 – 52.5 | Shoulder + pin Ø1.500 (DCN-6) | Fishing neck joint |

## 1.4 Subsystem design

### 1.4.1 Bottom equalizing sub (SHEX-013 / SHEX-013S) — DCN-5

A ported body with an internal sliding sleeve. At run-in the sleeve ports
align with the body ports (Z 4.0) so the tool cannot piston while running.
During the first 0.375 in of setting stroke the departing mandrel tail
shoulder carries the sleeve up to its closed stop (anti-rotation lug Ø0.093
riding the sleeve slot), blanking the ports between the two body O-ring
glands. To retrieve, down-jarring re-opens the sleeve and equalizes across
the plug before the seals release.

DCN-5 rebuilt this stack from the spec (which was unbuildable — §1.8): seals
moved to **internal body glands** (2× -016 Viton 90, 0.045 in deep in the
Ø1.476 bore) riding the plain Ø1.470 sleeve OD.

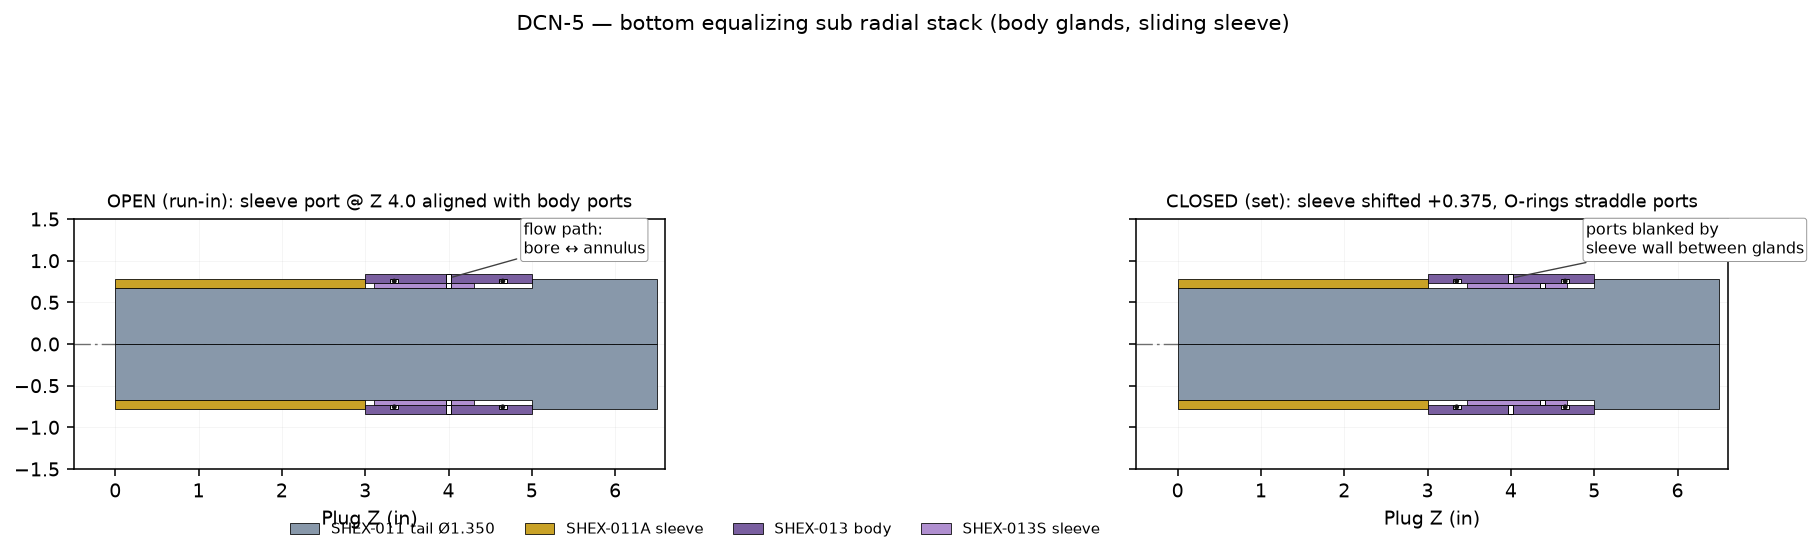
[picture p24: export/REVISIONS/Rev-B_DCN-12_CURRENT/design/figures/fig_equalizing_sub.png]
Equalizing sub


### 1.4.2 Slips (SHEX-006 upper / SHEX-007 lower)

Eight segments per set, wire-EDM profile parts (deployed radii R3.560 →
R4.360, set OD 8.720), four OD tooth serrations, teeth case-hardened to
55 HRC min over a 28–32 HRC core. Each set rides a 12°-included expander
taper on the mandrel; tooth rake on the lower set is mirrored so the pair
brackets the plug against load from either direction. At run-in the
segments nest as collapsed arcs inside the Ø1.688 carrier envelope.

### 1.4.3 Stage-1 / stage-2 stents (SHEX-008 / SHEX-009)

Laser-cut sleeves on Ø1.688 × 0.063-wall tube — the direct stent analogue.
Staggered circumferential kerf slots (closed-cell at run-in) deploy to a
diamond mesh: stage 1 to Ø3.375, stage 2 to Ø5.750. They are radial
scaffolding for the cascade — each stage provides the reaction base for the
next — not pressure barriers. Deployment foreshortening ≈22 % is verified
on first article (§2). Flat-pattern DXF authority:
`export/stent/developed_dxf/` (kerf-compensated).

### 1.4.4 Stage-3 iris (SHEX-010 + SHEX-002 + 16× SHEX-001) — DCN-1

The signature mechanism. Sixteen rigid 17-4 segments (22.5° each, deployed
radii R2.955 → R4.318, set OD 8.636) ride in guide slots of the fixed
support sleeve. Each segment has a follower tab engaged in the 2-start
internal helical grooves of the Inconel 718 guide insert. As the mandrel
strokes, its 2-start drive ribs (lead 4.000) sweep through the insert
grooves, converting axial stroke into rotation-plus-radial travel — the
segments screw outward like an iris aperture opening, 1.363 in of radial
travel per segment over the 4.0 in active zone.

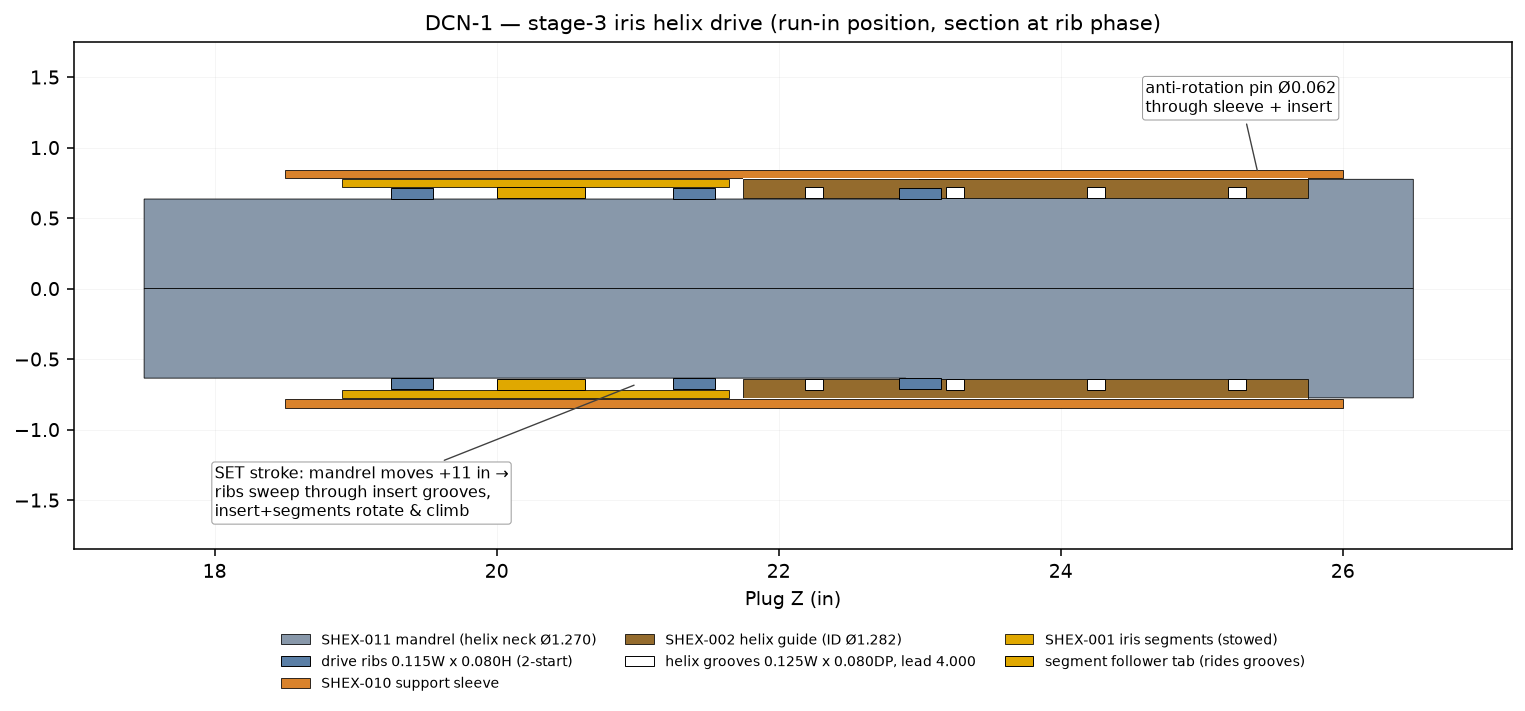
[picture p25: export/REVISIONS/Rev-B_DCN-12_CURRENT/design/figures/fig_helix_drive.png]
Helix drive


### 1.4.5 Seal lands ×4 (SHEX-004 + 16× SHEX-005)

Four identical 4.5 in lands. Each carries a molded HNBR 90A liner ring
backed by sixteen 17-4 anti-extrusion petals (deployed radii R0.895 →
R4.011). At full stroke the mandrel's four 3° seal ramps (Ø1.550→1.582)
arrive under the lands simultaneously and compress the deployed packs
against the casing wall (contact OD 8.720). The petals close the extrusion
gap behind the elastomer; four lands in series share the differential.

### 1.4.6 Upper MTM backup (12× SHEX-003)

Three rings of four 88° segments (joints staggered 30°), deployed radii
R4.200 → R4.400 (set OD 8.800 against casing ID 8.835). The mandrel's
Ø1.558 load land preloads the stack at end-of-stroke: a metal-to-metal
extrusion barrier above the elastomer seals for high-temperature /
high-differential holds.

### 1.4.7 Top joint (SHEX-011 ↔ SHEX-012) — DCN-6

Pin-up mandrel into box-down fishing neck: 1-1/2-12 UNF-2A × 1.000 thread
at the box mouth, plain Ø1.500 seal nose into a Ø1.530 seal bore, Parker
2-216 face seal in the pin nose end face, all shouldering at Z 51.0.
Cross-pinned Ø0.125 after 250 ft-lb makeup. Top connection 1 in AMT per
API 11BR for the setting-tool adapter and retrieval string.

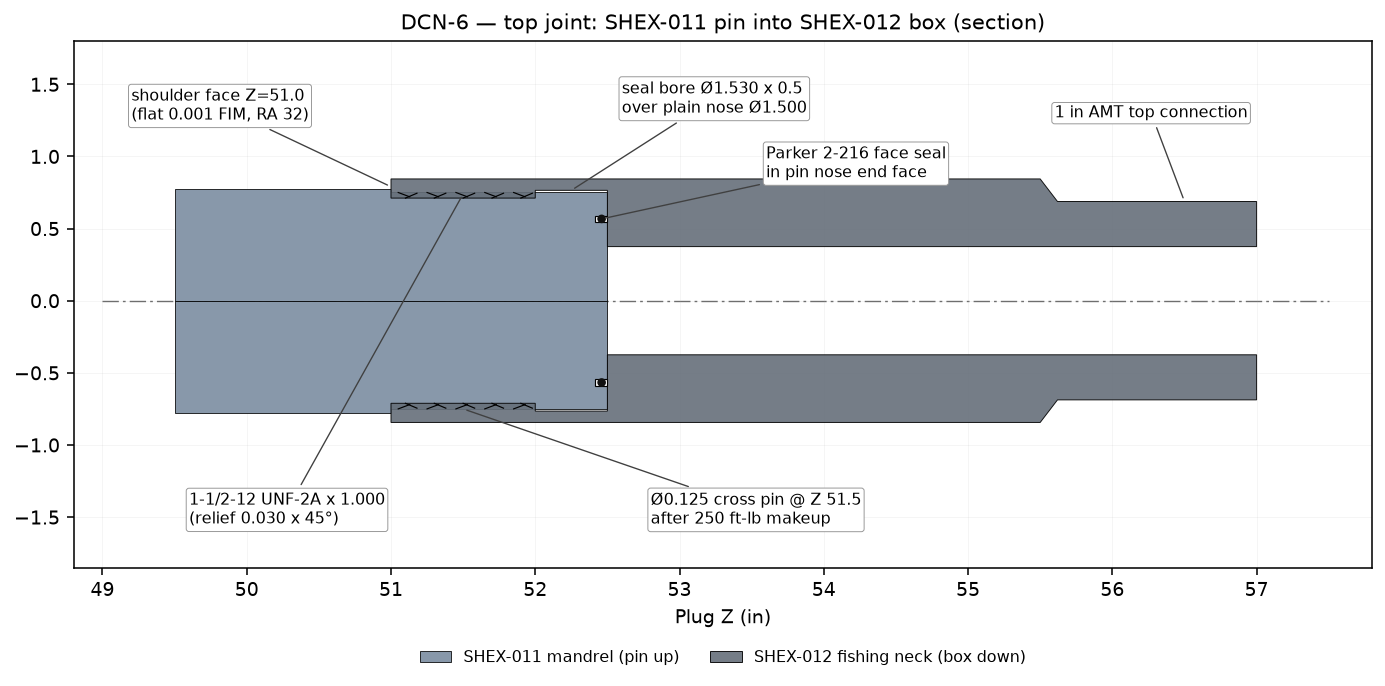
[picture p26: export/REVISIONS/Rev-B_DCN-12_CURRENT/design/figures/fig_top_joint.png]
Top joint


## 1.5 Setting sequence

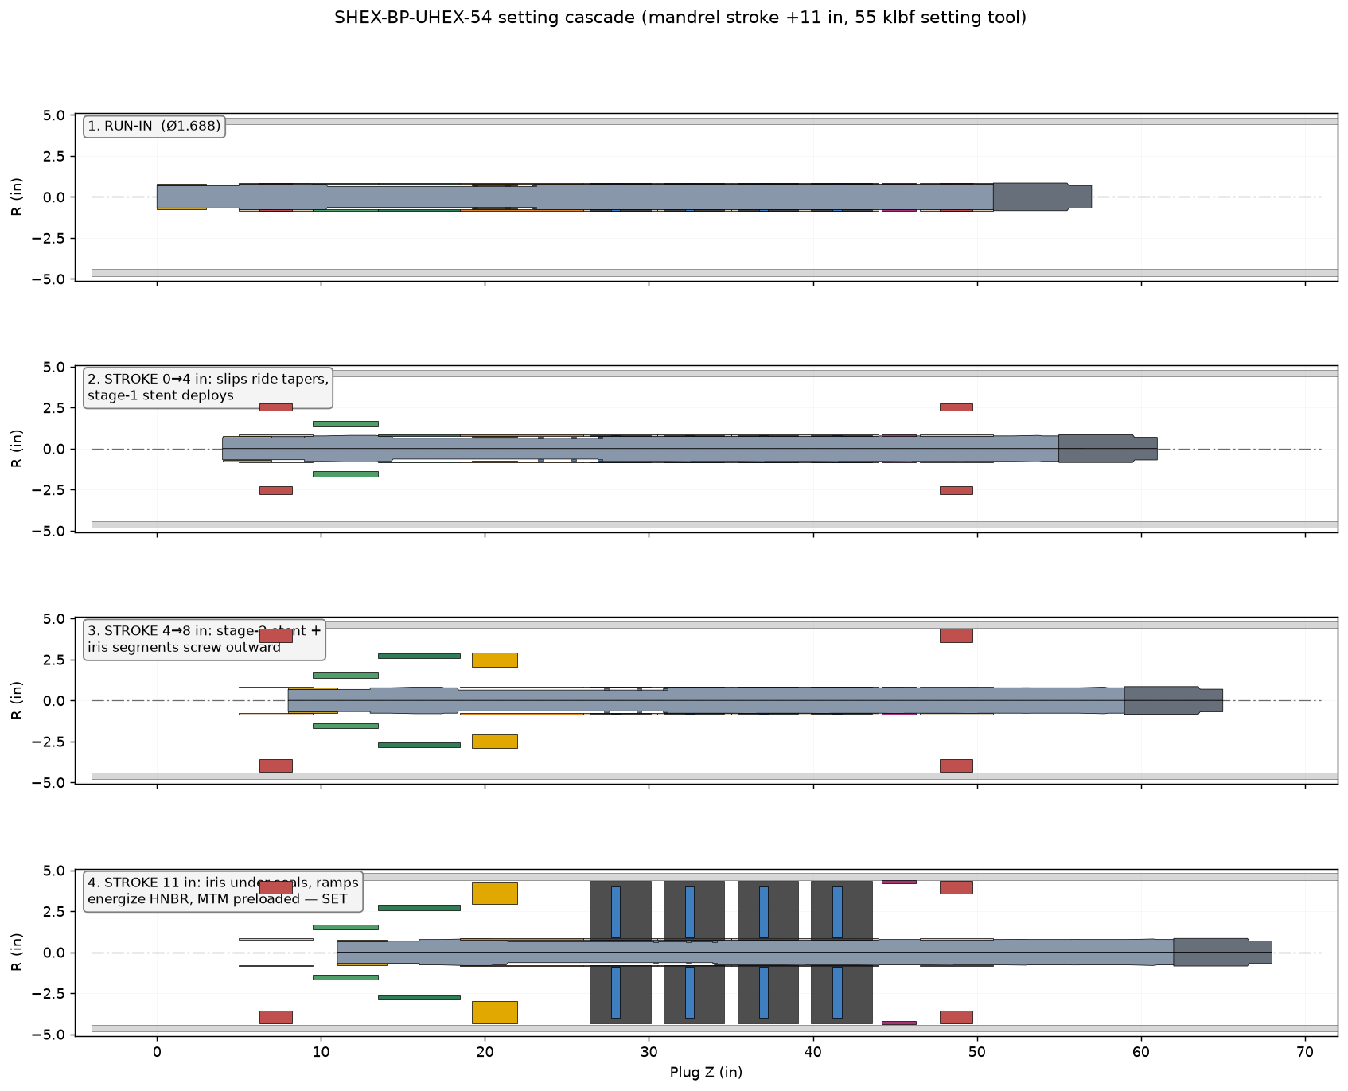
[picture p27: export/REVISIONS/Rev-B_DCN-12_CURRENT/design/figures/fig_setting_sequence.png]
Setting sequence


Stroke budget (total +11.0 in):

| Stroke (in) | Event |
|---|---|
| 0 – 0.375 | Mandrel tail carries equalizing sleeve to CLOSED stop |
| 0.375 – 4.0 | Slip tapers enter both slip sets; segments ride out and bite casing. Stage-1 stent deploys off its actuator |
| 4.0 – 8.0 | Stage-2 stent deploys; mandrel drive ribs traverse the helix insert — iris segments screw out to full radius |
| 8.0 – 11.0 | Four seal ramps arrive under the seal lands and energize the HNBR packs; MTM land Ø1.558 preloads the backup rings; setting tool shears off at release stud |

Set confirmation at surface: stroke counter = 11.0 ± 0.25 in and final
force ramp to ≥45 klbf without displacement.

## 1.6 Retrieval

1. Latch the Ø1.375 fishing neck with a standard 1.688-class GS pulling tool.
2. Jar down: mandrel strokes back, tail re-enters the equalizing sub and
   re-opens the sleeve — differential equalizes across the plug.
3. Continue down-stroke: seal ramps withdraw (HNBR relaxes), MTM preload
   releases, slip tapers withdraw (segments retract).
4. Straight pull retrieves the tool. The stents and iris do not fully
   re-collapse to Ø1.688; retrieval is to the next casing restriction above
   the setting depth only (not back through tubing). This is an accepted
   limitation of all ultra-high-expansion designs — see assumptions.

## 1.7 Materials summary

| Part | Material | Condition |
|---|---|---|
| SHEX-001/003/005/006/007/008/009/010/011 | 17-4 PH | H900 (H1150M where marked for toughness) |
| SHEX-002 helix guide | Inconel 718 | AMS 5662, aged |
| SHEX-004 liner | HNBR | 90 Shore A |
| SHEX-011A/012/013/013S | 4140 | HT 28–32 HRC (AMS 6415) |
| O-rings / face seal | Viton 90 | -016 ×2, 2-216 ×1 |

## 1.8 Engineering assumptions — read before relying on this design

These are every assumption of consequence baked into the released geometry,
grouped by how much risk they carry.

**A. Architecture-level assumptions (inherited from the original docs)**

1. **Stent extrapolation is valid at oilfield scale.** The cascade concept
   (each expansion stage scaffolds the next) is proven at millimetre scale
   in superelastic nitinol. Here it is implemented in 17-4 PH at 50× the
   size, where the material yields rather than recovering elastically. The
   design therefore relies on *plastic* expansion of the stent stages —
   they are formed in place and do not recover. Unvalidated by test.
2. **A 5.2:1 expansion ratio with a rigid-segment iris.** No industry
   precedent. The iris mechanism is kinematically sound (it is a lead screw)
   but the segment-to-casing load path at 8.6 in diameter from a 1.27 in
   mandrel is a long lever arm; segment tilt under differential is the
   first-order risk, reacted only by the support sleeve slot fit (0.120
   slot / 0.115 tab).
3. **Four elastomer lands in series share load equally.** In practice the
   uphole land takes most of the differential until it extrudes into its
   backup. The 4-land redundancy is treated as a series safety chain, not
   an equal load share.
4. **3,000–5,000 psi target.** `config/design_uhex_54in.yaml` retains a
   note that 0.125 segment thickness was "marginal at 5000 psi" in the FEA
   baseline and production thickness was raised to 0.187. No release-grade
   FEA exists for the as-released geometry (§1.10).

**B. Geometric reconciliations (the DCN log)**

The part specs contradicted each other in six places; the released geometry
resolves them as follows. Full detail in `../RELEASE_NOTES.md`.

| DCN | Problem in spec | Resolution in release |
|---|---|---|
| 1 | Helix grooves 0.080 deep in a wall of 0.001 | Mandrel necked Ø1.270 (Z 10.4–23.0), 2-start ribs peak Ø1.429; insert ID 1.552→1.282 |
| 2 | Tail sleeve OD 1.350 < ID 1.352 | OD 1.550 / ID 1.352 |
| 3 | Ø1.550 mandrel stub vs Ø0.750 neck bore | Finished length 52.500: shoulder Z 51.0 + Ø1.500 pin |
| 4 | OAL 54.0 vs 6.000 neck | OAL 57.0 in |
| 5 | Eq-sub sleeve OD 1.680 can't enter ID 1.562 body; grooves cut through every wall | Body 1.688/1.476 w/ internal glands; sleeve 1.470/1.354; tail Ø1.350 extended to Z 5.0 |
| 6 | Counterbore-at-mouth female cannot seal | Thread at mouth, seal bore deeper, face seal in pin nose |

**C. Run-in representation**

5. **Rigid profile parts cannot be "crimped" like stents.** The original
   docs say the iris segments, petals, slips and MTM segments are "nested
   and crimped to 1.688 OD" — impossible for rigid parts whose deployed
   radial width exceeds the run-in annulus (iris radial width 1.363 vs
   annulus 0.063). In the released run-in model these parts are shown as
   thin nested arcs *representing stowed position kinematics, not true part
   geometry*. The real tool requires either (a) segments machined as
   multi-leaf telescoping laminates, or (b) acceptance that deployed-profile
   parts ride *outside* a smaller-diameter core at run-in. **This is the
   single largest unresolved design question in the inherited concept.**
   The individual part STEPs and drawings are always true manufacturing
   geometry.
6. Stent slot patterns are modelled at 0.020 in display width; the
   manufacturing kerf is 0.008 (drawing + flat-pattern DXF authority).

**D. Quantitative assumptions**

7. Setting force ≤55 klbf, stroke 11.0 of the tool's 12.0 available.
8. Friction: lead-screw drive assumed self-locking in reverse under seal
   load (helix angle ≈ 40° on Ø1.35 pitch — *not* self-locking by
   classical criterion; the set position is actually held by the setting
   tool's body-lock ring, an assumption inherited from the setting tool
   spec, SHEX-ST-54).
9. Casing assumed 9-5/8 40# L80, nominal ID 8.835, no wear, no ovality.
   MTM set OD 8.800 leaves 0.035 diametral standoff (rings seat on
   pressure-assist, not interference).
10. HNBR 90A rated 150 °C continuous; tool is **not** an HPHT design.
11. Thread capacity: 1-1/2-12 UNF-2A engaged 1.000 in 17-4/4140 — shear
    area ≈ 2.4 in², far above the 55 klbf setting load (×10 margin); the
    Ø0.125 cross pin only locks rotation.
12. All module bores Ø1.562 over the Ø1.550 mandrel: 0.012 diametral
    running clearance, RA 32 travel zones — assumes verticality/no-debris
    during stroke; no debris barriers are designed in yet.

## 1.9 Verification status

| Check | Status |
|---|---|
| Geometric consistency (parts vs assembly, both states) | Done — model builds clean |
| STEP integrity (round-trip, 1 solid/part, no orphans) | Done — see `../RELEASE_NOTES.md` |
| Mass/volume sanity | Done (volume table in release notes) |
| Drawing completeness vs BOM | Done — 14 sheets cover all 15 parts |
| FEA (segments, petals, mandrel, thread) | **Not done** |
| First-article stent deployment test | **Not done** |
| Elastomer qualification (RGD, temperature) | **Not done** |

## 1.10 Open items

1. Release-grade FEA: iris segment bending at 5,000 psi; petal extrusion
   gap; mandrel column buckling at 55 klbf over the Ø1.270 neck (the
   governing section, A = 1.27 in², λ slender over 12.5 in unsupported).
2. Resolution of assumption C-5 (true run-in stowage of profile parts).
3. Setting-tool interface drawing (SHEX-ST-54 adapter, shear stud value).
4. Stage-1/-2 stent actuators (SHEX-014 bladder / SHEX-015 belleville
   wedge) are referenced by the stent drawings but not yet designed.
5. Debris barriers / wipers for the Ø1.562 travel bores.

---

# Part 2 — Manufacturing guide

## 2.1 General requirements (apply to every part)

- Dimensions in inches. Unless otherwise specified: .XX ±0.010,
  .XXX ±0.005, angles ±0.5°, break sharp edges 0.010 max.
- 17-4 PH parts: solution treat + age per drawing (H900 default; H1150M
  where the sheet says so). **Cut all features before aging** unless noted;
  passivate per AMS 2700 after final machining.
- 4140 parts: AMS 6415, quench & temper 28–32 HRC before finish machining.
- All sealing surfaces RA 16; mandrel travel zones RA 32.
- Certs: full material traceability; heat-treat charts; final inspection
  report against the drawing's critical dimensions (marked below).
- Every part gets its part number + heat lot laser-etched in a
  non-functional surface.

## 2.2 Per-part process routes

Drawing references are the authority for every dimension; this section
defines the *route* and the features that decide accept/reject.

### SHEX-001 iris segment — qty 16 — DWG-001-SHP

17-4 PH plate, 2.750 thick (H1150M).
1. Wire-EDM the deployed arc profile (R2.955 / R4.318 × 22.5°) — this is a
   profile part, **not** a turned OD.
2. Machine the follower tab (0.625 × 0.125 × 0.080 radial) on the inner
   face, mid-length. Tab width 0.125 ±0.003 is the **critical fit** to the
   SHEX-002 groove.
3. Root fillets R0.030 min; outer toe chamfer 0.025 × 45° both faces.
4. Age, passivate, electropolish exposed faces.
5. Inspect: tab width/position, arc radii (CMM), segment mass match within
   ±2 g across the set of 16 (balance).

### SHEX-002 helix guide insert — qty 1 — DWG-002A-SHP

Inconel 718 bar Ø1.75.
1. Turn OD 1.555 / bore Ø1.282 / L 4.000.
2. Cut the 2-start internal helical grooves 0.125 W × 0.080 DP, lead
   4.000 — sinker EDM with a helical electrode or 5-axis mill. Groove
   root Ø1.442. Start phases 180° apart; phase reference flat on the OD.
3. Age per AMS 5662.
4. Inspect: groove width gauge pin drag over full helix; phase between
   starts ±0.5°; functional test with mandrel + 1 segment in the SHEX-010
   pocket before acceptance.

### SHEX-003 MTM ring segment — qty 12 — DWG-005-SHP

17-4 PH plate, 0.750 thick. Wire-EDM 88° arc R4.200/R4.400. Age H900,
passivate. Inspect arc radii; segments are interchangeable — no serial
matching needed.

### SHEX-004 HNBR seal liner preform — qty 4 — DWG-007B-SHP

Compression-mold HNBR 90A ring Ø1.662/Ø1.562 × 0.550. Mold the **run-in
preform only** (the 8.720 set shape forms downhole). Parting line
mid-thickness, draft 1° min, flash ≤0.010, no mold release in the seal
zone. Post-cure per compound data sheet; durometer check 90 ±3 Shore A.

### SHEX-005 petal backup — qty 64 — DWG-007A-SHP

17-4 PH plate, 0.550 thick. Wire-EDM 22.5° sector R0.895/R4.011. Root
fillet R0.015 min, toe chamfer 0.015 × 45° both faces. Age, passivate.
Petals nest in sets of 16 — deburr thoroughly; any burr stacks 16×.

### SHEX-006 / SHEX-007 slip segments — qty 8 + 8 — DWG-008A/B-SHP

17-4 PH plate, 2.000 thick.
1. Wire-EDM the 41° sector profile R3.560/R4.360.
2. Mill the 4 OD tooth serrations (0.060 deep) **before** case hardening.
   SHEX-007 tooth rake is mirrored versus SHEX-006 — do not mix blanks.
3. Case harden teeth 55 HRC min, 0.020–0.030 case, core stays 28–32 HRC
   (induction or selective carburize with copper masking).
4. Inspect: tooth profile template, case depth coupon, bore face finish
   (rides the mandrel expander taper).

### SHEX-008 / SHEX-009 stent sleeves — qty 1 + 1 — DWG-009/011-SHP

17-4 PH tube Ø1.688 × 0.063 wall (or gun-drilled bar).
1. Laser-cut the slot pattern from the kerf-compensated flat-pattern DXF
   (`export/stent/developed_dxf/` is authority; kerf 0.008).
2. SHEX-008: 12 cells × 6 rings on L 4.000. SHEX-009: 14 cells × 4 rings
   on L 5.000.
3. Heat treat H900 **after** cutting; electropolish; zero burrs or recast
   slag (dye-pen the slot ends — crack initiation sites).
4. First article: deploy a sacrificial sleeve on the expansion die to set
   OD (3.375 / 5.750) and record foreshortening (expect ≈22 %); adjust
   pattern release only with engineering approval.

### SHEX-010 support sleeve — qty 1 — DWG-012-SHP

17-4 PH bar Ø1.75.
1. Turn OD 1.688 / bore Ø1.562 / L 7.500; helix pocket bore Ø1.558 over
   Z' 3.250–7.250; retaining-ring groove 0.030 × 0.040 at Z' 7.200.
2. Broach or wire-EDM the 16 internal guide slots 0.120 W × 0.055 DP ×
   2.750 L (slot centres Z' 2.375, indexed 22.5°). Slot width 0.120
   +0.003/-0.000 is the **critical fit** to the segment bodies.
3. Age H900, passivate. Deburr — no burrs in the helix pocket.
4. Inspect: slot index ±0.25°, pocket diameter (the SHEX-002 press/slip
   seat), bottom pilot Z' 0–0.750 (mates the stage-2 stent top).

### SHEX-011 inner mandrel — qty 1 — DWG-011B-SHP

17-4 PH bar Ø1.75 × 54 (solid — no through bore).
1. Rough turn the full OD ledger oversize 0.020; stress relieve.
2. Finish turn all zones per the ledger (§1.3 table): tail Ø1.350, body
   Ø1.550, slip tapers Ø1.620, helix neck Ø1.270, 4× seal ramps Ø1.582
   crest, MTM land Ø1.558, pin Ø1.500.
3. Mill/whirl the 2-start drive ribs Z 19–23 (round form 0.115 W ×
   0.080 H, lead 4.000, peak Ø1.429). Phase reference to the same flat
   used on SHEX-002.
4. Single-point the 1-1/2-12 UNF-2A × 1.000 thread; relief 0.030 × 45°.
   Face-groove the pin nose for the Parker 2-216 (OD 1.181 / ID 1.087 ×
   0.086 DP).
5. Age H900 (fixture vertically — straightness 0.005 per 12 in is the
   **critical spec**); finish-grind travel zones to RA 32.
6. Inspect: full ledger on CMM; rib lead and phase versus the SHEX-002
   functional gauge; straightness; thread gauge 2A.

### SHEX-011A tail sleeve — qty 1 — DWG-011A-SHP

4140 HT tube. Turn OD 1.550 / ID 1.352 × 3.000; chamfers 0.040/0.030 ×
45°. Slip fit over the Ø1.350 tail — verify by hand fit at assembly, no
shake.

### SHEX-012 fishing neck / top sub — qty 1 — DWG-010-SHP

4140 HT bar Ø1.75.
1. Turn body Ø1.688 × 4.5, pin section Ø1.375 × 1.5; through-bore Ø0.750.
2. Bore the female end per DCN-6: thread zone at the mouth (tap drill
   Ø1.4224, 1-1/2-12 UNF-2B × 1.000), then seal bore Ø1.530 × 0.500
   deeper, RA 16.
3. Cut the 1 in AMT top connection per API 11BR; gauge before ship.
4. Inspect: thread gauge 2B, seal bore finish/diameter, squareness of the
   bottom face to the thread axis 0.002 FIM (it is the joint shoulder).

### SHEX-013 equalizing sub body — qty 1 — DWG-013-SHP

4140 HT bar Ø1.75.
1. Turn OD 1.688 / bore Ø1.476 × 2.000.
2. Cut 2 internal gland grooves Ø1.566 × 0.098 W (0.045 deep) straddling
   the port plane per DCN-5.
3. Drill 4× Ø0.062 radial ports at Z' 1.000, 90° apart; deburr from the
   bore side (seal surface).
4. Drill the Ø0.093 × 0.250 DP anti-rotation pin seat at Z' 0.500.
5. 100 % pressure test all ports after machining.

### SHEX-013S sliding sleeve — qty 1 — DWG-013-SHP (view B)

4140 HT tube. Turn OD 1.470 / ID 1.354 × 1.200; drill 4× Ø0.062 ports at
Z' 0.900 matching the body pattern; mill the anti-rotation slot. OD is the
**dynamic seal surface** — RA 16, no scratches. Functional test in the
body: free travel 0.375 min without binding; flow open / blocked closed.

## 2.3 Bill of materials

| Item | Part | Qty | Material | Drawing |
|---|---|---|---|---|
| 1 | SHEX-011 inner mandrel | 1 | 17-4 PH H900 | DWG-011B-SHP |
| 2 | SHEX-013S sliding sleeve | 1 | 4140 HT | DWG-013-SHP |
| 3 | SHEX-013 equalizing sub body | 1 | 4140 HT | DWG-013-SHP |
| 4 | SHEX-011A tail sleeve | 1 | 4140 HT | DWG-011A-SHP |
| 5 | SHEX-007 lower slip segment | 8 | 17-4 PH, case teeth | DWG-008B-SHP |
| 6 | SHEX-008 stage-1 stent | 1 | 17-4 PH H900 | DWG-009-SHP |
| 7 | SHEX-009 stage-2 stent | 1 | 17-4 PH H900 | DWG-011-SHP |
| 8 | SHEX-001 iris segment | 16 | 17-4 PH H900 | DWG-001-SHP |
| 9 | SHEX-002 helix guide insert | 1 | Inconel 718 | DWG-002A-SHP |
| 10 | SHEX-010 support sleeve | 1 | 17-4 PH H900 | DWG-012-SHP |
| 11 | SHEX-004 HNBR liner | 4 | HNBR 90A | DWG-007B-SHP |
| 12 | SHEX-005 petal backup | 64 | 17-4 PH H900 | DWG-007A-SHP |
| 13 | SHEX-003 MTM ring segment | 12 | 17-4 PH H900 | DWG-005-SHP |
| 14 | SHEX-006 upper slip segment | 8 | 17-4 PH, case teeth | DWG-008A-SHP |
| 15 | SHEX-012 fishing neck | 1 | 4140 HT | DWG-010-SHP |
| 16 | O-ring -016 Viton 90 | 2 | FKM 90 | (seal kit) |
| 17 | Parker 2-216 Viton 90 | 1 | FKM 90 | (seal kit) |
| 18 | Cross pin Ø0.125 | 1 | 17-4 PH | (hardware kit) |
| 19 | Anti-rotation pins Ø0.062 / Ø0.093 | 1 + 1 | 17-4 PH | (hardware kit) |

---

# Part 3 — Assembly guide

Audience: shop service hand, bench assembly. Tool builds **horizontally on
V-blocks**, bottom (tail) to the left. Plug Z increases to the right.

## 3.1 Before you start

**Tooling:** V-block fixture rail ≥60 in; strap wrenches; thread compound
(API modified); Viton-safe O-ring lube; torque wrench to 300 ft-lb;
Ø0.125 / Ø0.093 / Ø0.062 drift pins and a 2 oz hammer; retaining-ring
pliers; segment nesting collet (SHEX-F-01 fixture); crimp die set
(SHEX-F-02); calipers + 0–2 in micrometer.

**Parts:** complete kit per BOM §2.3, every machined part with its
inspection report. Wash all parts; blow dry. **No dry assembly of seals.**

**Orientation rule:** every module slides on from the **pin (top) end** of
the mandrel and travels left (down-tool) to its Z station, except the
bottom group (steps 2–4) which loads from the tail end.

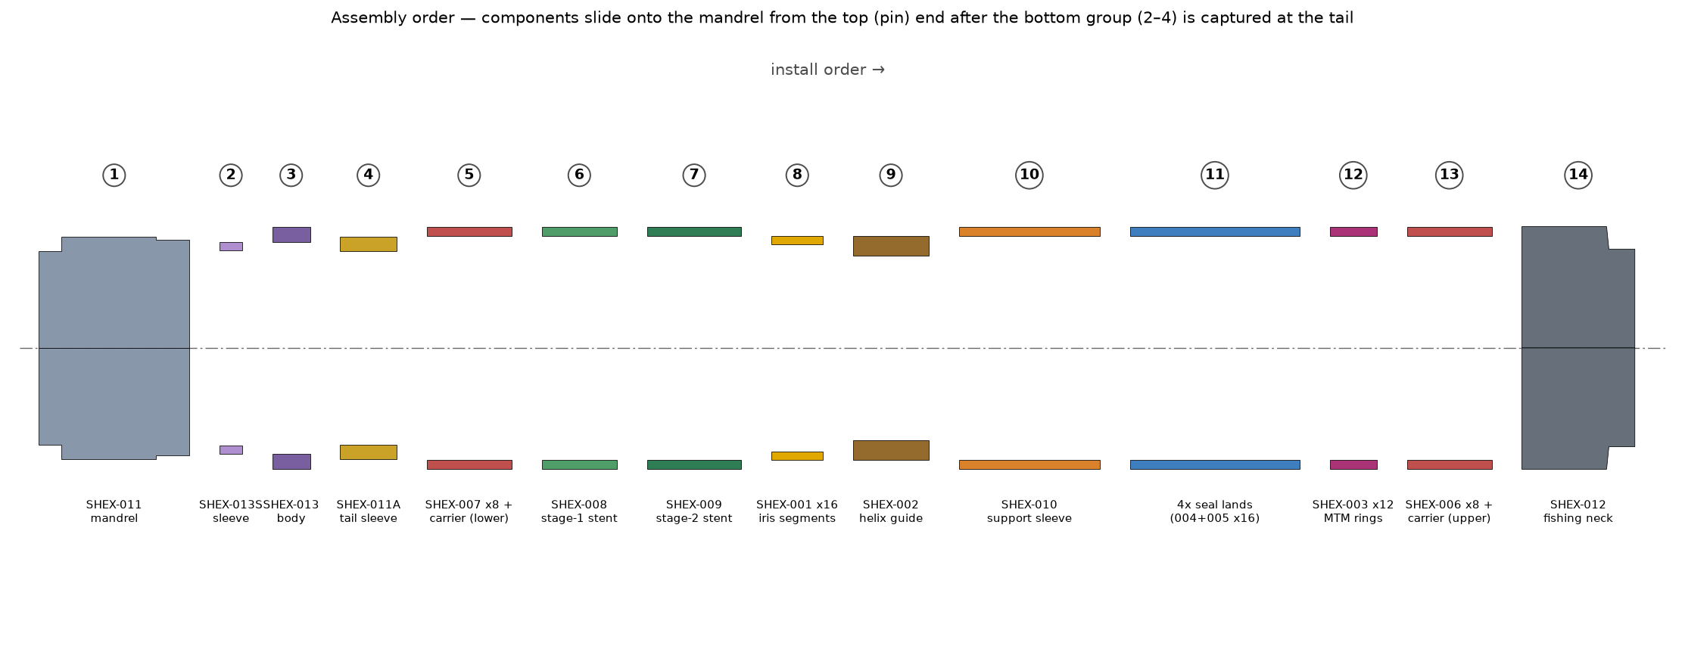
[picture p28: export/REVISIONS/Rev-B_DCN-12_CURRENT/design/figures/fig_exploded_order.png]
Assembly order


## 3.2 Build sequence

Numbers match the figure above.

**Step 1 — Mandrel on blocks.**
Set SHEX-011 in the V-blocks, tail (Ø1.350 end) left. Wipe travel zones;
verify no handling dings on the seal ramps (Z 27–42) — any raised metal
fails the build.

**Step 2 — Equalizing sleeve.**
Lube the SHEX-013S OD lightly. Slide it over the tail from the left, ports
facing up, to Z ≈ 3.1. It rides the Ø1.350 tail loosely until the body
captures it.

**Step 3 — Equalizing sub body.**
Fit the 2× -016 O-rings into the internal body glands (lube, do not roll
or twist). Slide SHEX-013 over the tail and over the sleeve to Z 3.0–5.0.
Install the Ø0.093 anti-rotation pin through the body seat into the sleeve
slot; stake. **Check:** sleeve shifts hand-force +0.375 and back without
binding; in the down (open) position the port stack is visually aligned
(flashlight through opposing ports).

**Step 4 — Tail sleeve.**
Slide SHEX-011A over the tail to Z 0–3.0, flush with the mandrel end at
Z 0. It backs the equalizing group from below.

**Step 5 — Lower slips.**
Position the lower slip carrier over Z 5.0–9.5. Nest the 8× SHEX-007
segments into the carrier windows **teeth up-hole** (rake holds from
below — the etched arrow on each segment points up-tool). Retain with the
carrier bands. Segments must sit below Ø1.688 — check with the ring gauge.

**Step 6 — Stage-1 stent.**
Slide SHEX-008 to Z 9.5–13.5, weld-seam datum line up. It pilots against
the slip carrier top face. No fasteners — axial capture comes from the
neighbouring modules.

**Step 7 — Stage-2 stent.**
Slide SHEX-009 to Z 13.5–18.5, datum up. Its top face is the pilot seat
for the support sleeve.

**Step 8 — Iris segments into the support sleeve (bench sub-assembly).**
On the bench, drop the 16× SHEX-001 segments into the SHEX-010 guide slots
using the nesting collet (SHEX-F-01), follower tabs inward. Hold with the
collet sleeve.

**Step 9 — Helix guide into the support sleeve.**
Press SHEX-002 into the sleeve pocket (Ø1.558 seat) until it lands at
Z' 3.250, **phase flat aligned to the sleeve witness mark** — the grooves
must pick up all 16 follower tabs; rotate the insert slowly while pressing
until every tab clicks in. Install the retaining ring at Z' 7.200, then the
Ø0.062 anti-rotation pin through sleeve + insert; stake.
**Check:** with the collet removed, rotating the insert by hand must walk
all 16 segments radially in and out together, no skipping.

**Step 10 — Iris module onto the mandrel.**
Slide the completed module over the pin end to Z 18.5–26.0. As the insert
reaches the drive-rib zone, rotate the whole module until the mandrel ribs
engage the insert grooves (witness mark on sleeve aligns with mandrel
phase flat at run-in). Seat against the stage-2 stent pilot.

**Step 11 — Seal lands ×4.**
For each land, lowest first (Z 26.0 / 30.5 / 35.0 / 39.5):
slide on the carrier; nest 16× SHEX-005 petals into the carrier window
(toe out-hole); seat the SHEX-004 HNBR liner above the petals (it grips the
carrier mechanically — no adhesive). Verify each pack sits under Ø1.688.
**Do not lube the HNBR OD.**

**Step 12 — MTM rings.**
Slide the 3 rings of 4× SHEX-003 segments into the Z 44.0–46.5 carrier
zone, **ring joints staggered 30°** ring-to-ring (witness dots align to
the 0/30/60 marks).

**Step 13 — Upper slips.**
As step 5 at Z 46.5–51.0 with 8× SHEX-006, **teeth down-hole** (mirror of
the lower set — etched arrow points down-tool).

**Step 14 — Fishing neck.**
Grease the 2-216 face seal into the mandrel pin nose groove. Dope the
1-1/2-12 UNF threads lightly. Make up SHEX-012 to the shoulder —
**250 ft-lb minimum** — then drill/ream the Ø0.125 cross-pin hole through
the pre-spotted location at Z 51.5, drive the pin, stake both ends.

## 3.3 Final checks (mandatory, record on the build sheet)

| # | Check | Accept |
|---|---|---|
| 1 | Ring-gauge full length | Ø1.688 gauge passes end to end |
| 2 | OAL | 57.00 ± 0.06 in |
| 3 | Equalizing valve | open at run-in position; hand-shift closes |
| 4 | Iris drive | rotating insert walks all 16 segments; returns free |
| 5 | Module stack | no axial shake > 0.015 total (feeler at fishing-neck shoulder) |
| 6 | Joint | cross pin staked; face seal not pinched (boroscope port) |
| 7 | Etch | tool S/N, date, build tech on fishing neck flat |

## 3.4 Run-in preparation note

Per assumption C-5 (§1.8), the profile-part packs (iris, petals, slips,
MTM) are **nested**, not crimped: final radial compaction to the running
gauge is done in the crimp die set (SHEX-F-02) which closes the carriers'
retaining bands — it does not plastically deform the segments. If any pack
springs over Ø1.688 after die release, the build fails and that module is
re-nested. The stent sleeves run as-machined (they are already at Ø1.688).

## 3.5 Torque & pin table

| Joint | Spec |
|---|---|
| SHEX-012 to mandrel pin | 250 ft-lb min, shoulder contact, then cross pin |
| Cross pin Ø0.125 | drive fit, stake 2 places |
| Anti-rotation pin Ø0.093 (eq sub) | press to 0.250 depth, stake |
| Anti-rotation pin Ø0.062 (helix) | press through sleeve + insert, stake |
| Setting-tool adapter (1 in AMT) | per setting-tool manual (SHEX-ST-54) |

---

# Appendix A — File index

| Content | Path |
|---|---|
| This manual | `export/release/manual/MANUAL.md` |
| Manual figures (source) | `export/release/manual/figures.py` |
| Part STEP files (15) | `export/release/step/parts/` |
| Assembly STEP run-in / set | `export/release/step/assemblies/` |
| Manufacturing drawings PDF/DXF | `export/release/drawings/` |
| DCN log + verification | `export/release/RELEASE_NOTES.md` |
| Machine-readable BOM | `export/release/manifest.json` |
| 3D preview renders | `export/release/png/` |
| Geometry source (authority) | `cad/release_solids.py`, `generate_release.py` |
| Stent flat patterns | `export/stent/developed_dxf/` |
| Legacy concept docs | `docs/DESIGN.md`, `export/drawings/part_specs/` |

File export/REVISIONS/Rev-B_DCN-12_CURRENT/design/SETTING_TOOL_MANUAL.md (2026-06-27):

# SHEX-AK-20 Setting Adapter Kit

## Setting-Tool Engineering, Manufacturing & Operations Manual

| | |
|---|---|
| Document | SHEX-MAN-002 Rev A |
| Companion plug | SHEX-BP-UHEX-54 (see `MANUAL.md`) |
| Kit | SHEX-AK-20 adapter kit (ST-101…104) |
| Interface | Baker #20 (E-4 No. 20 e-line **and** Model J No. 20 CT) |
| Net set stroke | 10.0 in + 0.25 overtravel = 10.25 in demand (DCN-8) |
| Release | calibrated shear stud, 45 klbf ±5% (ST-DCN-2) |
| Geometry authority | `cad/setting_kit_solids.py` → `../step/parts/ST-*.stp` |
| Drawings | ST-DWG-101/102/103 in `../drawings/` |

**Contents**

- [Part 0 — Why an adapter kit, not a bespoke tool](#part-0--why-an-adapter-kit-not-a-bespoke-tool)
- [Part 1 — Engineering design](#part-1--engineering-design)
- [Part 2 — Market tool selection](#part-2--market-tool-selection)
- [Part 3 — Manufacturing guide](#part-3--manufacturing-guide)
- [Part 4 — Rig-up & operations guide](#part-4--rig-up--operations-guide)
- [Part 5 — Assumptions & open items](#part-5--assumptions--open-items)
- [Appendix A — File index](#appendix-a--file-index)

---

# Part 0 — Why an adapter kit, not a bespoke tool

The repo contains an earlier concept for a **bespoke electro-mechanical
setting tool** (`SHEX-ST-54`: 246 in, 3.625 OD, BLDC motor + ball screw,
12 in stroke, 55 klbf — see `First Pass Files/docs/SETTING_TOOL_DETAIL.md`).
That path is **parked**. A qualified downhole electro-mechanical setting tool
is a multi-year, multi-million-dollar program (motor, battery, telemetry,
20 ksi/350 °F packaging) and duplicates tools that already exist on every
service-company truck.

**This deliverable instead adapts the plug to standard, field-proven setting
tools** — exactly how every specialty plug reaches the market. The plug top
(DCN-7) and stroke budget (DCN-8) were already reshaped to a **Baker #20**
interface, and Baker confirms the **Model J** coiled-tubing hydraulic tool
"is the same size as the Model E-4 … and uses the same adaptor kits."
So **one kit (SHEX-AK-20) serves both e-line and coiled tubing.**

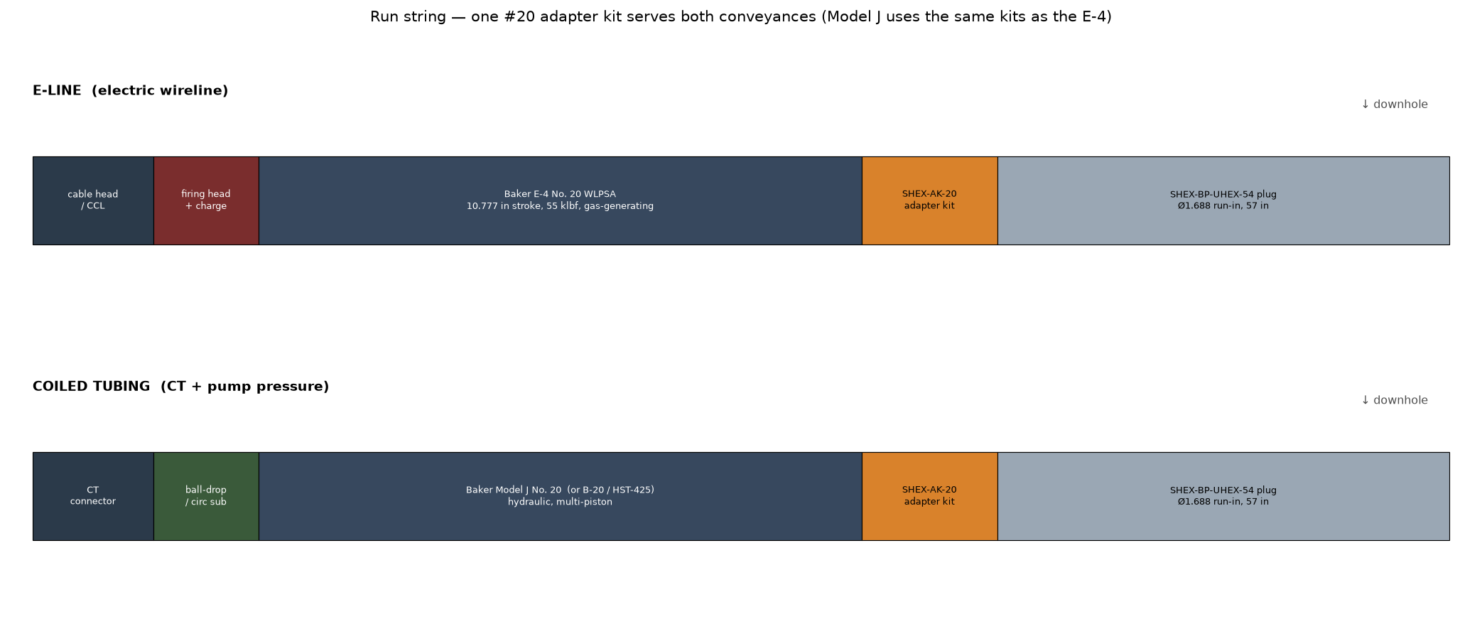
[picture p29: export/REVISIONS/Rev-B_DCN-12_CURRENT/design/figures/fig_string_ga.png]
Run string


---

# Part 1 — Engineering design

## 1.1 The setting problem is split between two actuators

The plug is deliberately a **two-actuator machine**, and understanding this is
the key to the whole setting design. There are two distinct "strokes":

1. **First stroke — internal, self-powered.** The two stent stages expand
   *radially* from energy stored inside the plug: a burst-disk-fired HNBR
   bladder (stage 1, SHEX-014) and a Belleville stack (stage 2, SHEX-015).
   These are triggered by the arming/burst event — **not** by the setting
   tool. This is the "first stroke initiated somehow."
2. **Secondary stroke — the setting tool.** Only after the internal stages
   have opened the plug to Ø5.75 does the setting tool apply its single
   **axial 10.0 in stroke** to finish the job: stage-3 iris, four seal
   lands, and the dual slips, then shear free.

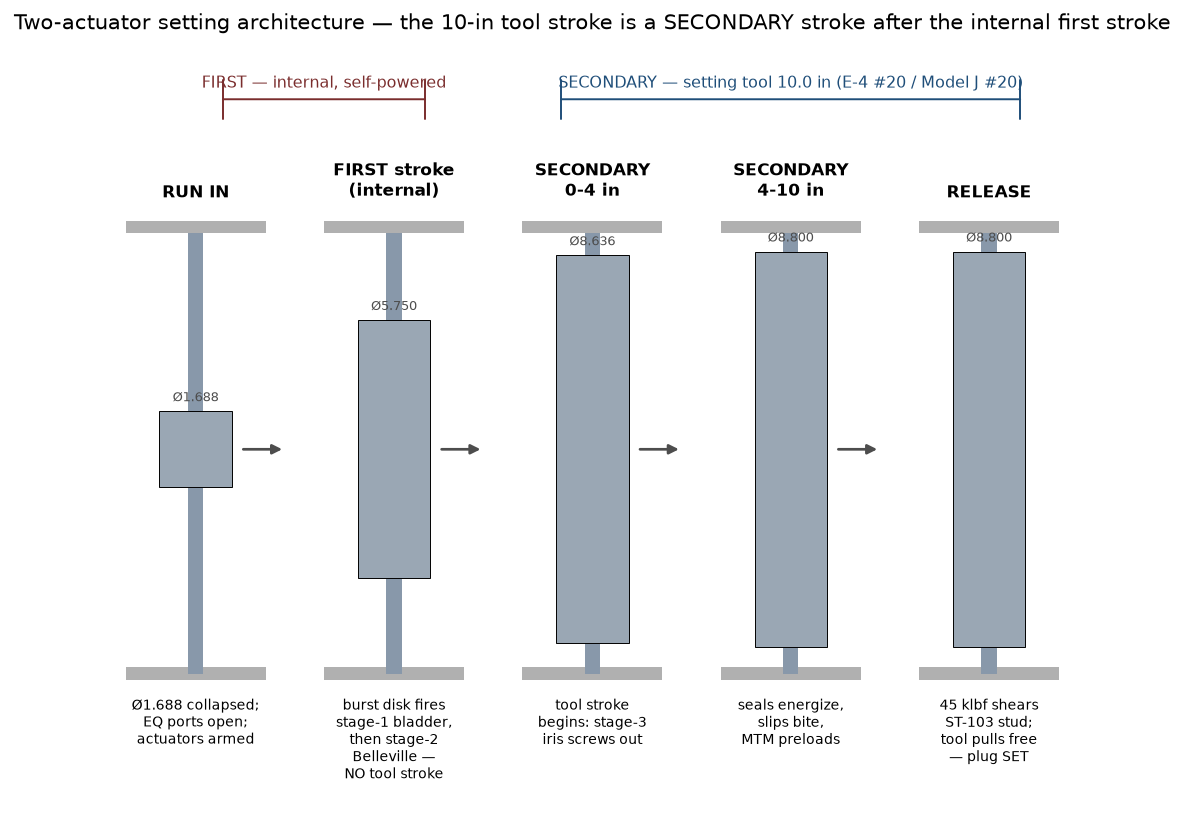
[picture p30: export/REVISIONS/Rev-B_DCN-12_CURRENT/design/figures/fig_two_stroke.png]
Two-actuator architecture


This split is what makes the plug settable at all. If the setting tool had to
do *all* the expansion (Ø1.688 → Ø8.8), the force and stroke would exceed any
market tool. By offloading the two big radial stages to internal actuators,
the tool only has to deliver the **residual** axial work.

> Important consequence: a **single-stroke** market tool (pyrotechnic E-4 or
> single-shot CT hydraulic) is sufficient, because the internal stages fire
> *before* the tool strokes. The tool does not need to "stroke, wait, stroke
> again." The sequencing happens between independent mechanisms.

## 1.2 How the adapter kit transmits the stroke

A setting tool produces **relative axial motion** between two members:
a **moving sleeve** (the crosslink/setting sleeve) and a **fixed mandrel**
(the setting mandrel/rod). The kit couples these to the plug:

- **ST-101 setting sleeve/shoe** threads onto the tool's moving sleeve and its
  foot lands on the plug's **upper slip carrier face** at plug Z = 51
  (the outer stack).
- **ST-102 tension rod** threads onto the tool's fixed mandrel and holds the
  plug **inner mandrel** through the fishing neck.
- **ST-103 shear stud** ties the rod to the plug fishing-neck box and sets the
  **release load** (45 klbf).
- **ST-104 spacers** tune the rig-up stand-off / stud preload.

When the tool strokes, the sleeve drives **down 10.0 in relative to the rod**.
Because the rod holds the mandrel up (through the neck) and the sleeve pushes
the outer stack down (through the carrier), the **outer stack displaces −10.0
in relative to the mandrel = SET**.

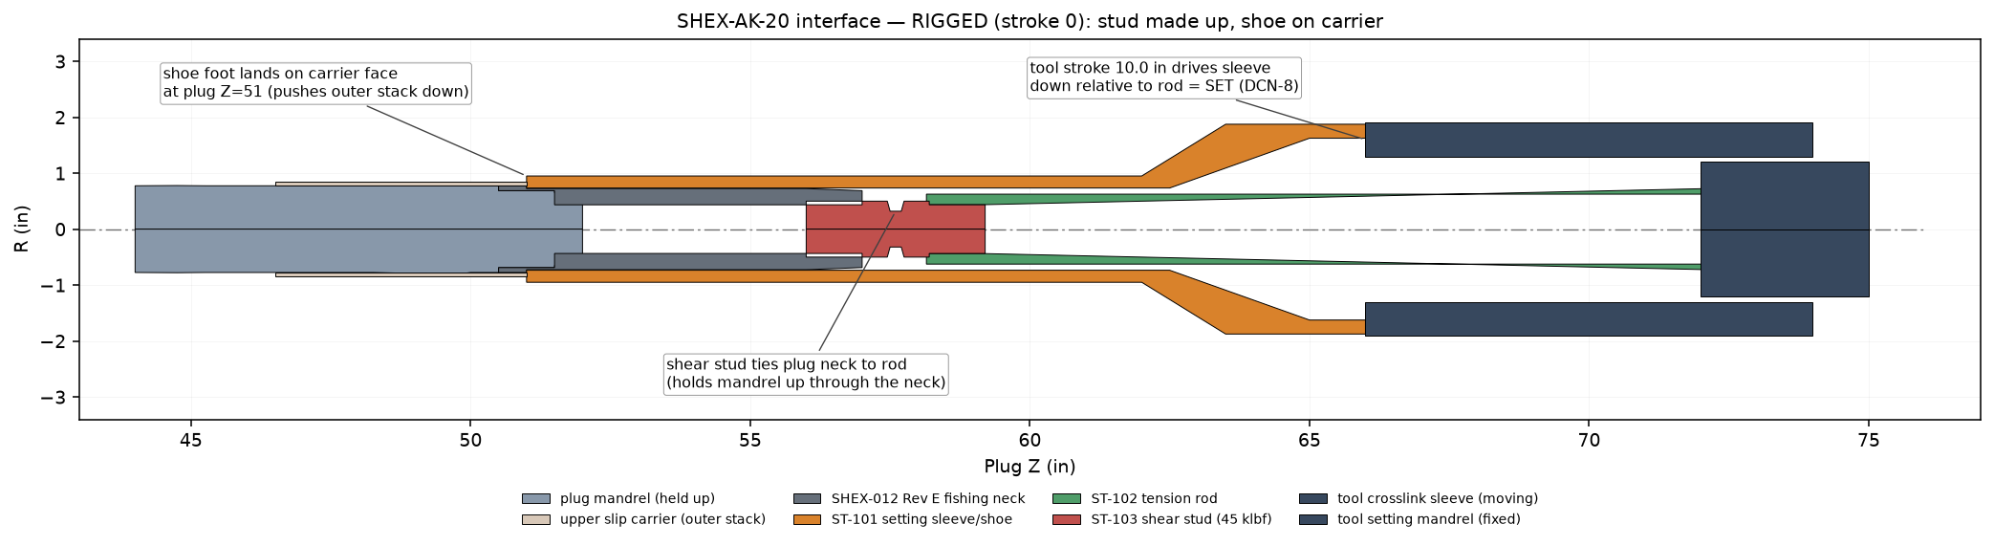
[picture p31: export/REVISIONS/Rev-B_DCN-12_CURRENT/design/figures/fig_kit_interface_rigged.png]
Interface — rigged


At the calibrated release load the stud parts at its neck; the string (tool +
rod + sleeve + upper stud half) lifts off, leaving the GS-profile fish head
(DCN-7) for later retrieval.

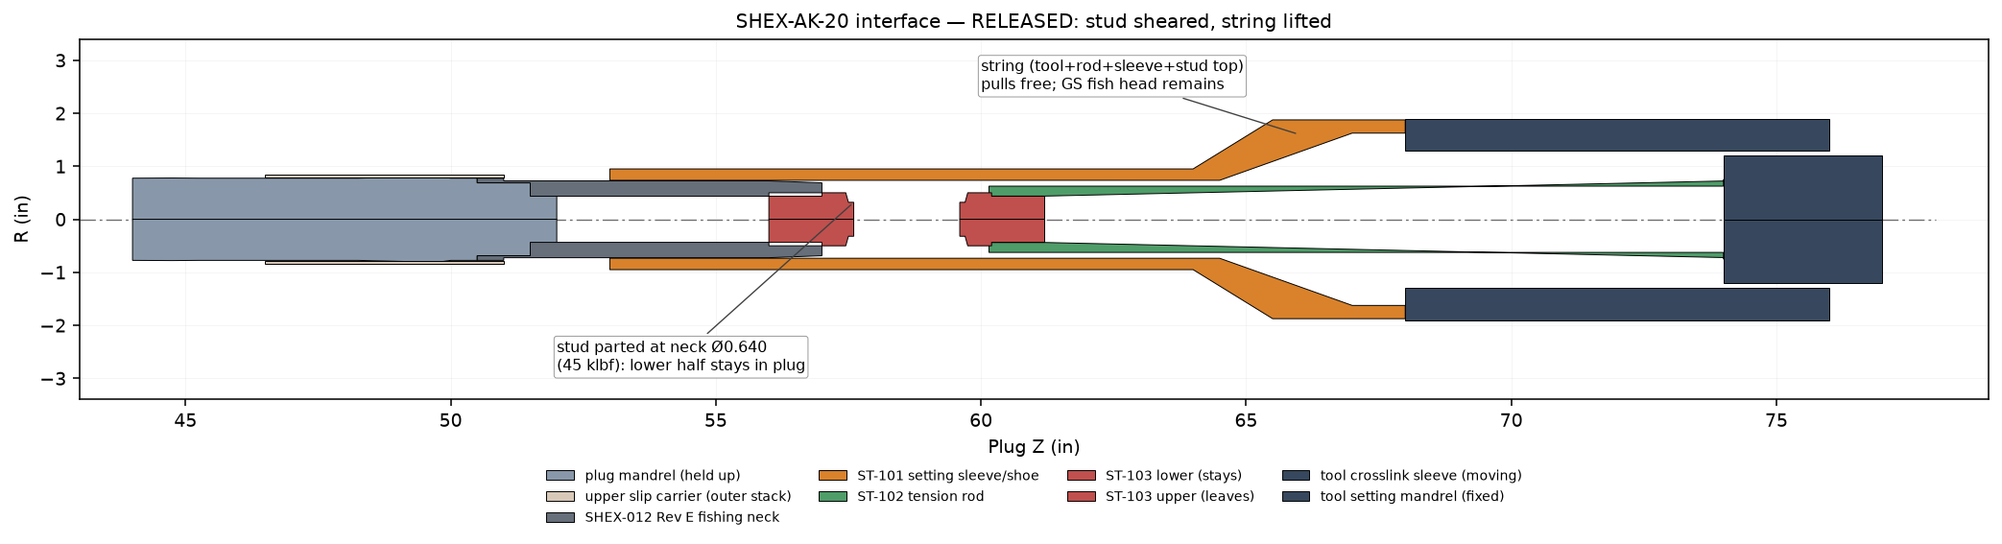
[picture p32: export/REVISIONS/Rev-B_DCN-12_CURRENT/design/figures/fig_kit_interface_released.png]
Interface — released


## 1.3 Kit dimensions (authority: `cad/setting_kit_solids.py`)

| Part | Key dimensions (in) | Material |
|---|---|---|
| ST-101 setting sleeve/shoe | L 15.000; shoe OD 1.900 / bore Ø1.470 × 11.0; cone to OD 3.750; box 3.250-8 UN × 2.0 | 4140 HT 28–32 HRC |
| ST-102 tension rod | L 15.100; body Ø1.250; bottom box 1.000-8 UN × 1.0; top pin 1.500-12 UNF × 1.25 | 4140 HT 28–32 HRC |
| ST-103 shear stud | L 3.200; bodies Ø1.000; **neck Ø0.640 × 0.200**; 1.000-8 UN pins both ends | 4140 HT 125–145 ksi lot |
| ST-104 stroke spacer | OD 1.900 / ID 1.480 × 0.250 (kit of 2) | 4140 HT |

Verified from STEP (re-imported): each part 1 solid, 0 orphan surfaces;
ST-101 L 15.000, ST-102 L 15.100, ST-103 L 3.200, ST-104 L 0.250.

## 1.4 Release-load design (ST-DCN-2)

The shear stud is the only calibrated element. Neck Ø0.640 in 4140 at
125–145 ksi UTS gives a shear-area parting load of **45 klbf ±5%**, set so the
tool releases *after* the plug is fully set but *below* the #20 tool's
55 klbf capacity (10 klbf margin) and below the rod tensile capacity
(min section 1.227 in², ~37 ksi nominal at 45 klbf). Lot calibration is
mandatory (Part 3).

---

# Part 2 — Market tool selection

## 2.1 Candidate tools (web-verified specs)

| Tool | Conveyance | Mechanism | Stroke (in) | Max force (lbf) | OD (in) | Interface |
|---|---|---|---|---|---|---|
| Baker E-4 #05 | e-line | gas/pyro | 5.879 | 10,000 | 1.718 | #05 |
| Baker E-4 #10 | e-line | gas/pyro | 5.707 | 35,000 | 2.750 (HD 3.800) | #10 |
| **Baker E-4 #20** | **e-line** | gas/pyro | **10.777** | **55,000** | 3.800 (HD 4.125) | **#20** |
| **Baker Model J #20** | **CT** | hydraulic | matches E-4 #20 | pressure × pistons | = E-4 #20 | **#20 (same kits)** |
| TechWest B20 / Renown B-20 | CT | hydraulic | ~10–11 | 50,000 (stud) | 3.8–4.25 | #20 |
| Pinnacle HST 425 | CT | hydraulic | 11 | pressure × pistons | Baker 20 conn | #20 |
| MAP MHSB / Fury HST | CT | hydraulic | model-dependent | pressure × pistons | #10 / #20 | #10/#20 |
| TechWest B105 / Renown B-10 | CT | hydraulic | ~6 | low (thru-tbg) | 1.81 | #10-class |

Sources: Baker Hughes E-4 technical unit; Owen MAN-SET-E410; RepeatPrecision;
Pinnacle, TechWest, MAP, Renown, Alpha product literature (logged in
`WORKING_LOG.md`).

## 2.2 The OD-versus-force conflict (the central finding)

The plug needs ~45 klbf and 10 in. Only the **#20** class delivers that — and
the #20 is **~3.8 in OD**. A 3.8 in tool **cannot pass through 2-3/8 or 2-7/8
production tubing**. The only tools slim enough to pass small tubing (E-4 #05
at 1.718 in, B105 at 1.81 in) top out near **10 klbf / 6 in** — far short.

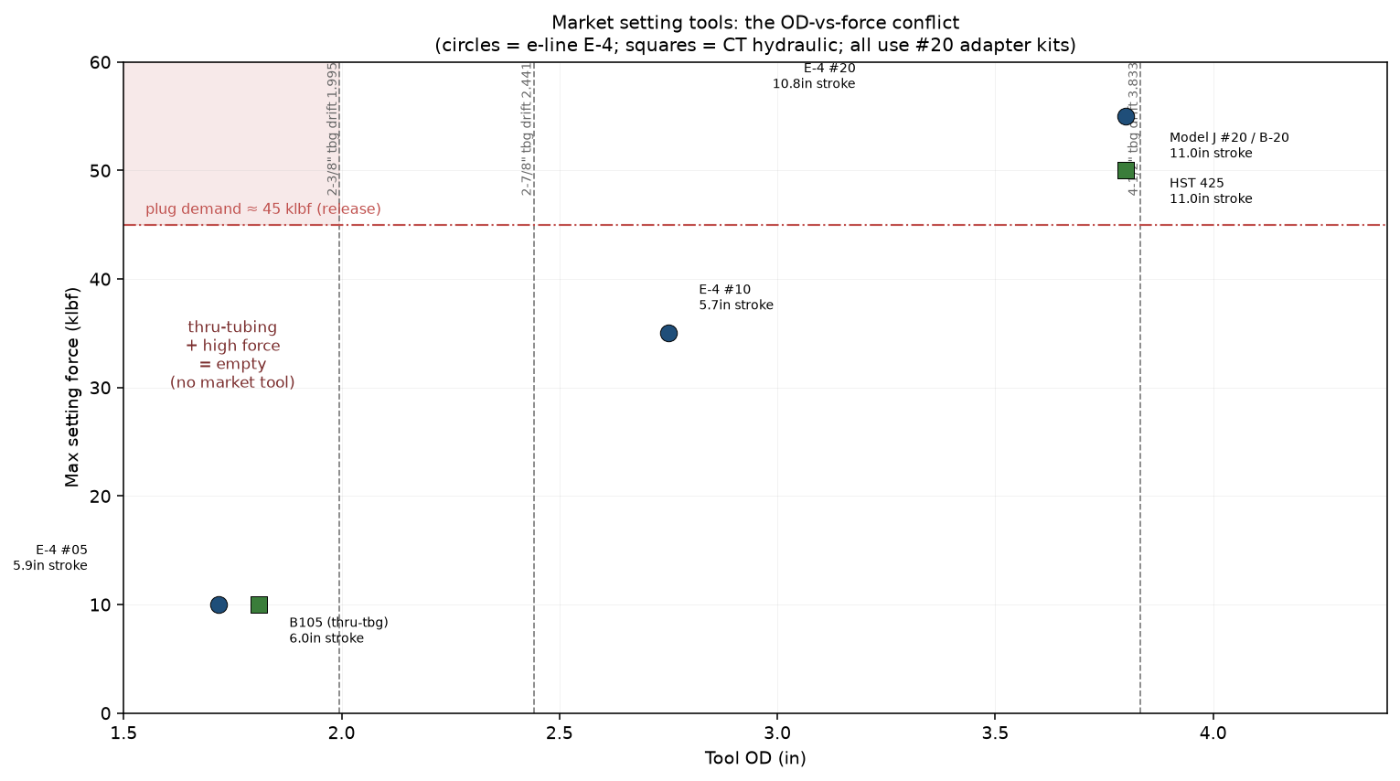
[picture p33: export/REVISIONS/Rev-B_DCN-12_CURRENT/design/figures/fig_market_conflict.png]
Market conflict


There is **no market tool that is simultaneously thru-tubing-slim and
45-klbf-strong.** This drives the deployment decision:

- **SHEX-AK-20 (#20) — selected.** Deploy in **casing or large-bore tubing/
  liner (≥ ~4-1/2 in)** where a 3.8 in tool reaches setting depth. This is the
  realistic way to get 45 klbf with an off-the-shelf tool. The plug's Ø1.688
  run-in OD then buys ultra-high expansion ratio and minimal set-depth
  restriction, **not** literal small-tubing passage *with the tool attached*.
- **True small-tubing thru-tubing** (tool ≤ 1.9 in) would cap the setting
  force near 10 klbf, which is only feasible if the seal and slip systems are
  redesigned to be **pressure-energized** (set by applied wellbore/annulus
  pressure) rather than **stroke-energized**. Logged as an open redesign item
  (Part 5).

## 2.3 Stroke budget

With stages 1–2 internal, the tool stroke only feeds stage-3 + seals + slips:

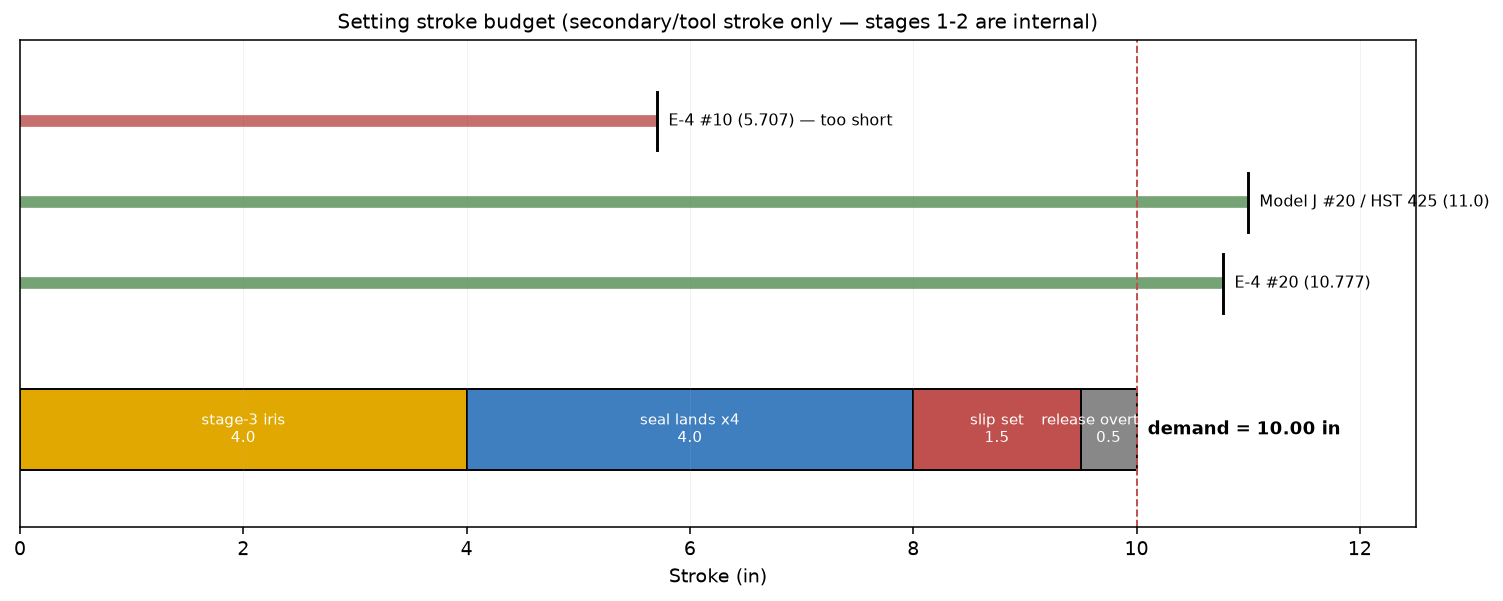
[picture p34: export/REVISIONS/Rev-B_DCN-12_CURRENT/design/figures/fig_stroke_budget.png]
Stroke budget


| Function | Stroke (in) |
|---|---|
| Stage-3 iris deploy | 4.0 |
| Seal lands ×4 | 4.0 |
| Slip set | 1.5 |
| Release overtravel | 0.5 |
| **Demand** | **10.0** (DCN-8; +0.25 ≈ 10.25 with margin) |

E-4 #20 (10.777) and Model J #20 / HST 425 (≈11) both clear it. E-4 #10
(5.707) is **too short** — do not substitute down a size.

## 2.4 Recommended selections

| Conveyance | Primary tool | Alternates |
|---|---|---|
| Electric wireline | **Baker E-4 No. 20 WLPSA** (slow-set charge) | E-4 #20 HP/HT for >400 °F |
| Coiled tubing | **Baker Model J No. 20** | TechWest B20, Renown B-20, Pinnacle HST 425, MAP MHSB-20 (all #20, same kits) |

All share the #20 bottom interface, so the SHEX-AK-20 kit fits all of them —
**confirm the specific tool's crosslink-sleeve and setting-mandrel threads
against ST-DCN-3 before cutting a kit** (clone vendors vary).

---

# Part 3 — Manufacturing guide

## 3.1 General

- Dimensions in inches; tolerances per drawing. Unless noted: .XX ±0.010,
  .XXX ±0.005, angles ±0.5°, break edges 0.010 max.
- ST-101/102/104: 4140 AMS 6415, Q&T to **28–32 HRC** before finish machining.
- ST-103: 4140 from a **single calibrated heat lot, 125–145 ksi UTS**.
- MPI all parts after machining; no linear indications on load members.
- Etch part no + heat lot in a non-functional surface.

## 3.2 Per-part routes

### ST-101 setting sleeve/shoe — DWG-ST-DWG-101

1. Turn OD: shoe Ø1.900 × 11.0, cone to Ø3.750, top body Ø3.750.
2. Bore: shoe bore Ø1.470 +.005/−.000 × 11.5 (passes the Rev E neck body
   Ø1.450); 30° cone bore; 3.250-8 UN-2B box × 2.0.
3. **Shoe foot face**: square 0.002 FIM to the bore axis, RA 32 — it bears on
   the slip carrier annulus (Ø1.562–1.688) at plug Z = 51.
4. 4× milled wrench flats 0.75 W at the top OD.
5. **Critical**: the Ø1.900 × 11.0 shoe tube is a slender column at 45 klbf —
   no nicks/tool marks deeper than 0.005; check straightness.
6. MPI; verify box thread on the chosen tool's crosslink sleeve (ST-DCN-3).

### ST-102 tension rod — DWG-ST-DWG-102

1. Turn body Ø1.250; runout body-to-threads 0.003 FIM max.
2. Bottom box 1.000-8 UN-2B × 1.0 (takes the stud top pin); top pin
   1.500-12 UNF-2A × 1.25 (tool setting mandrel).
3. Wrench flats 2× 1.000 AF at mid-body. Radius all shoulders R0.06 min
   (fatigue — this is a full-tension member at 45 klbf, ~37 ksi nominal).
4. MPI.

### ST-103 calibrated shear stud + ST-104 spacer — DWG-ST-DWG-103

1. Machine stud: bodies Ø1.000, **neck Ø0.640 × 0.200**, 1.000-8 UN-2A pins
   both ends, 0.500 hex socket in the top end face. 45° neck shoulders,
   root R0.015 **max** (controlled break — do **not** polish, plate, or
   shot-peen the neck).
2. **Lot calibration (mandatory):** pull **3 studs per heat lot to failure**;
   accept the lot only if all 3 part within **42.75–47.25 klbf**. Stamp lot
   no + break load on both body flanks.
3. ST-104 spacer: OD 1.900 / ID 1.480 × 0.250, kit of 2.

## 3.3 Kit bill of materials

| Item | Part | Qty/kit | Material | Drawing |
|---|---|---|---|---|
| 1 | ST-101 setting sleeve/shoe | 1 | 4140 HT 28–32 HRC | ST-DWG-101 |
| 2 | ST-102 tension rod | 1 | 4140 HT 28–32 HRC | ST-DWG-102 |
| 3 | ST-103 shear stud | 1 (+spares) | 4140 HT 125–145 ksi lot | ST-DWG-103 |
| 4 | ST-104 stroke spacer | 2 | 4140 HT | ST-DWG-103 |
| 5 | Setting tool (E-4 #20 or Model J #20) | 1 | service-company asset | — |
| 6 | Plug GS pulling tool (retrieval) | 1 | 1.375 GS class | — |

---

# Part 4 — Rig-up & operations guide

Audience: wireline/CT crew at the rig. The plug ships **pre-assembled and
ring-gauged** (see plug `MANUAL.md` Part 3). This section covers connecting
the setting tool through the SHEX-AK-20 kit and running the set.

## 4.1 Pre-job checks

- Confirm the setting tool is a **#20** class with the expected crosslink-sleeve
  and setting-mandrel threads (matches ST-DCN-3, or re-cut the kit).
- Confirm the **shear stud lot certificate** (break load 42.75–47.25 klbf).
- Confirm casing/large-bore tubing ID at setting depth admits the **tool OD
  (~3.8 in)** all the way to depth — this kit is **not** for small-tubing
  passage with the tool attached (Part 2.2).
- Inspect the plug fishing neck (Rev E): GS profile, seal bore, top box.

## 4.2 Surface make-up (rig floor)

Make up bottom → top, hand-tight then torqued:

1. **ST-103 stud into the plug fishing-neck top box** (1.000-8 UN), hex-socket
   makeup. This is the calibrated release joint — do not over-torque.
2. **ST-102 rod onto the stud top pin**, then rod top pin into the **tool
   setting mandrel** box (1.500-12 UNF). The rod now holds the plug mandrel
   to the tool's fixed member.
3. Slide **ST-101 sleeve** over the plug fishing neck so its foot rests on the
   upper slip carrier face (plug Z = 51); thread its 3.250-8 UN box onto the
   **tool crosslink sleeve** (moving member).
4. Fit **0/1/2 ST-104 spacers** between the sleeve box face and the tool sleeve
   to take up stand-off so there is **no slack** in the load path at stroke 0.
5. Verify by hand: the kit is rigid, the shoe foot is square on the carrier,
   and the stud is the only tension tie between rod and plug.

For **e-line**: connect the firing head + CCL above the tool. For **CT**:
connect the CT connector + circulation/ball-drop sub above the tool.

## 4.3 Run in

- Convey tool + kit + plug as one string. Plug at Ø1.688; **equalizing sub
  ports OPEN** so the string does not piston.
- Correlate depth (CCL on e-line; depth counter / tag on CT).
- Do **not** apply set force during run-in.

## 4.4 Set sequence

| Step | e-line (E-4 #20) | coiled tubing (Model J #20) |
|---|---|---|
| 1 | At depth, hold tension; confirm position | At depth, tag/space out |
| 2 | **First stroke (internal):** arm/fire burst disk → stage-1 bladder, then stage-2 Belleville. Plug Ø1.688 → 5.75. **No tool action.** | same — internal, pressure/time triggered |
| 3 | **Secondary stroke:** fire E-4 power charge → single 10.0 in gas-driven stroke | **Secondary stroke:** drop/seat ball, pressure up CT → multi-piston 10.0 in stroke |
| 4 | Stroke drives stage-3 iris (0–4 in), then 4 seal lands + slips (4–10 in) | same |
| 5 | Load builds to **45 klbf → ST-103 stud shears**; tool releases | load builds to 45 klbf → stud shears; tool releases |
| 6 | Bleed off (E-4 disk bleeder) before POOH | CT ports open automatically; circulate/equalize |

**Set confirmation:** e-line — the power-charge stroke completes and tension
drops at release; CT — pump pressure spikes then drops at shear, tubing drains
on POOH. Pressure-test from above per program.

## 4.5 Release & retrieval

- After shear, the **string + upper stud half** pull free; the **lower stud
  half + GS fish head** remain on the plug.
- To retrieve the plug later: run a **1.375 GS pulling tool**, latch the fish
  head, jar **down** to re-open the equalizing sub and equalize, then straight
  pull (see plug `MANUAL.md` §1.6). Retrieval is to the next restriction above
  setting depth, not back through small tubing.

## 4.6 Torque & calibration table

| Joint | Spec |
|---|---|
| ST-103 stud → plug neck box | hand + defined makeup (do not exceed shear preload) |
| ST-102 rod → stud / tool mandrel | 1.500-12 UNF, standard makeup |
| ST-101 sleeve → tool crosslink sleeve | 3.250-8 UN, standard makeup + spacers |
| ST-103 release | 45 klbf ±5% (lot-calibrated, certificate required) |

---

# Part 5 — Assumptions & open items

## 5.1 Assumptions baked into this kit

1. **Deployment in casing / large bore.** The #20 tool OD (~3.8 in) reaches
   setting depth. The plug is **not** run through 2-3/8/2-7/8 tubing *with the
   #20 tool attached* (Part 2.2). If literal small-tubing thru-tubing is
   required, this kit does not apply.
2. **Internal stages 1–2 do the radial heavy lifting.** The 10 in / 45 klbf
   tool budget is only valid because the bladder (SHEX-014) and Belleville
   (SHEX-015) expand the plug to Ø5.75 first. Those actuators and their
   trigger/equalizing-sleeve interlock are **referenced but not yet designed.**
3. **45 klbf release is an estimate.** The true iris+seal+slip resistance is
   unverified (plug FEA open item). The stud neck is easily re-calibrated when
   FEA or first-article setting data exists.
4. **Tool-side threads (ST-DCN-3) are assumed** (3.250-8 UN crosslink sleeve,
   1.500-12 UNF setting mandrel). Confirm against the specific tool make/serial
   before cutting a kit; #20 clones vary.
5. **Single-shot set.** Both the E-4 (pyrotechnic) and a ball-drop CT tool set
   in one continuous stroke; there is no provision for a partial set / re-set
   in this kit.

## 5.2 Open items (carried in `FORWARD_PLAN.md`)

- Resolve the thru-tubing force conflict: either accept casing/large-bore
  deployment (current) or re-architect seals+slips as pressure-energized for a
  ≤1.9 in / ≤10 klbf thru-tubing tool.
- Setting-force FEA → finalize the 45 klbf release value.
- Design SHEX-014 bladder and SHEX-015 Belleville actuators and the
  equalizing-sleeve trigger interlock (the "first stroke").
- Verify ST-DCN-3 threads against the chosen tool; add a Schlumberger-interface
  variant if required.

---

# Appendix A — File index

| Content | Path |
|---|---|
| This manual | `export/release/manual/SETTING_TOOL_MANUAL.md` |
| Manual figures (source) | `export/release/manual/figures_setting.py` |
| Kit geometry (authority) | `cad/setting_kit_solids.py`, `generate_setting_kit.py` |
| Kit STEP parts | `export/release/step/parts/ST-101…104_*.stp` |
| Kit interface assemblies | `export/release/step/assemblies/SHEX-AK-20_INTERFACE_{RIGGED,RELEASED}.stp` |
| Kit drawings | `export/release/drawings/{dxf,pdf}/ST-DWG-101/102/103*` |
| Kit manifest | `export/release/manifest_setting_kit.json` |
| 3D previews | `export/release/png/SHEX-AK-20_*` |
| Working log / plan | `WORKING_LOG.md`, `FORWARD_PLAN.md` |
| Plug manual | `export/release/manual/MANUAL.md` |
| Setting sequence (legacy) | `First Pass Files/docs/SETTING_SEQUENCE.md` |
| Parked bespoke tool | `First Pass Files/docs/SETTING_TOOL_DETAIL.md` |

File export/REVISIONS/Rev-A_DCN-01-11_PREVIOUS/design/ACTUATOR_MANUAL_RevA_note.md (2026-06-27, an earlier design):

# Actuator scope at Rev A (DCN-10/11)

At Rev A the stage-1/2 internal actuators are the **two inflatable bladders +
Belleville hold** (DCN-10 ductile stent, DCN-11 second bladder). The first-stroke
**trigger / equalizing interlock was still an open item** at this revision.

It is engineered at **Rev B (DCN-12)** — see
`../../Rev-B_DCN-12_CURRENT/design/ACTUATOR_MANUAL.md` (Rev B) and
`../../Rev-B_DCN-12_CURRENT/engineering/FIRST_STROKE_TRIGGER.md` (SHEX-EM-001),
which add the SHEX-017 sequence/initiation sub.

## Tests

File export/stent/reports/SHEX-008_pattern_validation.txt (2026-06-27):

SHEX-008 (DWG-009) — developed diamond pattern

RUN-IN (laser authority)
  OD 1.688 / bore ID 1.562 / L 4.000
  Developed W 5.105 / pitch 0.425 / 12 cells × 6 rings
  Strut width 0.045 / kerf 0.008

SET envelope (validation target)
  OD 3.375 / bore ID 1.450
  Target pitch 0.632 (1.485× circumferential stretch)
  Deploy length ~3.115 (foreshorten 0.885 in, 22.1%)
  Strut edge length (run-in) 0.4113 in

  Circumferential stretch run->SET mean pitch: 1.485× (OD ratio 1.999×)
  Estimated deploy length: 3.115 in (foreshorten 0.885 in, 22.1%)

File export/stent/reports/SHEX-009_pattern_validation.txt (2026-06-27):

SHEX-009 (DWG-011) — developed diamond pattern

RUN-IN (laser authority)
  OD 1.688 / bore ID 1.562 / L 5.000
  Developed W 5.105 / pitch 0.365 / 14 cells × 4 rings
  Strut width 0.045 / kerf 0.008

SET envelope (validation target)
  OD 5.750 / bore ID 3.375
  Target pitch 1.024 (2.808× circumferential stretch)
  Deploy length ~3.935 (foreshorten 1.065 in, 21.3%)
  Strut edge length (run-in) 0.7557 in

  Circumferential stretch run->SET mean pitch: 2.808× (OD ratio 3.406×)
  Estimated deploy length: 3.935 in (foreshorten 1.065 in, 21.3%)

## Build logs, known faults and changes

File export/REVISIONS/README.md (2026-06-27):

# SHEX-BP-UHEX-54 — Revision Archive

Each folder below is a **self-contained snapshot** of one revision of the
complete tool: engineering, design, part-specs, drawings (dxf+pdf), step,
stl, and full-tool previews.

| Revision | Folder | DCNs | Complete tool (run-in / set) | What changed |
|---|---|---|---|---|
| **Rev B — CURRENT** | `Rev-B_DCN-12_CURRENT/` | DCN-01 … **DCN-12** | **47 / 48 bodies** | adds the **SHEX-017** sequence/initiation sub: commanded initiation + completion-gated sequencing + EQ pilot interlock (first-stroke trigger). |
| Rev A — previous | `Rev-A_DCN-01-11_PREVIOUS/` | DCN-01 … DCN-11 | 44 / 45 bodies | plug + setting kit + stage 1/2 bladder actuators; trigger still an open item. |

## Where the complete run-in & set tool live

- **Latest (Rev B):** `Rev-B_DCN-12_CURRENT/stl/full-tool/SHEX-BP-UHEX-54_FULL_RUN-IN.stl`
  and `..._FULL_SET.stl` (+ matching `.stp` in `step/full-tool/`).
- Previous (Rev A): same paths under `Rev-A_DCN-01-11_PREVIOUS/`.

## DCN history (full)

- DCN-01..06 — plug geometry resolutions (see `design/MANUAL.md`).
- DCN-07..09 — settability / 10-in stroke / iris re-index (`design/SETTING_TOOL_MANUAL.md`).
- DCN-10 — stent material → ductile expandable alloy.
- DCN-11 — stage-2 prime mover → second inflatable bladder (Belleville = hold only).
- DCN-12 — first-stroke initiation & sequencing → SHEX-017 (Rev B only).

*Generated by `build_revisions.py`. The canonical working copies remain under
`export/release/`, `export/full_tool/`, `export/analysis/`; this archive is the
clean per-revision view.*

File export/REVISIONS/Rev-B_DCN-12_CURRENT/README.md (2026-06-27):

# Rev B — DCN-12 (CURRENT)

Complete tool: **47 bodies (run-in) / 48 bodies (set)**.

Adds the **SHEX-017 sequence/initiation sub** (+ 017A arming sleeve, 017B
reference piston) implementing DCN-12: commanded initiation (CT applied
differential + ball seat, or e-line EFI gate), completion-gated sequencing, and
the EQ pilot interlocked to close first.

## Contents
- `engineering/` — analysis scripts + data, incl. `trigger_design.py` and
  `FIRST_STROKE_TRIGGER.md` (SHEX-EM-001).
- `design/` — `MANUAL.md`, `SETTING_TOOL_MANUAL.md`, `ACTUATOR_MANUAL.md`
  (Rev B), `figures/`.
- `part-specs/` — per-part shop specs.
- `drawings/dxf`, `drawings/pdf` — incl. **ACT-DWG-017**.
- `step/parts` — incl. **SHEX-017 / 017A / 017B**.
- `step/assemblies` — AK-20 interface + ACT-S12 subs (23 bodies, with 017).
- `step/full-tool`, `stl/full-tool` — **complete run-in & set tool** (47/48).
- `previews/` — full-tool isometric + section renders.

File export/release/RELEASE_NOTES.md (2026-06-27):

# SHEX-BP-UHEX-54 Release Package — Notes

Rev A — generated from `cad/release_solids.py` via `generate_release.py`.
All dimensions inch; STEP files exported in millimetres (1 in = 25.4 mm).
Tool axis = Z, bottom of tool at Z=0, increasing uphole.

## Contents

| Path | Contents |
|---|---|
| `step/parts/` | 15 individual part STEP files, one solid per file, body named via physical group |
| `step/assemblies/SHEX-BP-UHEX-54_RUN-IN.stp` | full tool, collapsed / run-in state (Ø1.688 envelope), 27 bodies |
| `step/assemblies/SHEX-BP-UHEX-54_SET.stp` | full tool, expanded / set state in 5.5-in 17# casing (casing included as reference body), 28 bodies |
| `stl/` | mesh exports of both assemblies for quick viewing |
| `drawings/dxf/`, `drawings/pdf/` | 14 manufacturing drawing sheets (DXF + PDF) |
| `png/` | rendered previews of assemblies, key parts, and sample sheets |
| `manifest.json` | machine-readable list of every export with material and qty per plug |
| `manual/MANUAL.md` | complete plug manual: engineering design + assumptions, manufacturing guide, assembly guide, with figures in `manual/figures/` |
| `step/parts/ST-101…104_*.stp` | SHEX-AK-20 setting adapter kit parts (sleeve, rod, shear stud, spacer) |
| `step/assemblies/SHEX-AK-20_INTERFACE_{RIGGED,RELEASED}.stp` | kit-to-plug-to-tool interface, made-up and post-shear states |
| `manifest_setting_kit.json` | machine-readable kit BOM |
| `manual/SETTING_TOOL_MANUAL.md` | setting-tool manual (SHEX-MAN-002): design, market selection, manufacturing, rig-up/operations |
| `step/parts/SHEX-014*/015*/016*/017*.stp` | stage 1/2 internal actuator parts (bladder glands, lock ring, charge sub, Belleville + housing, charge chamber, EQ pilot, **SHEX-017 sequence sub + 017A arming sleeve + 017B reference piston, DCN-12**) |
| `step/assemblies/SHEX-ACT-S12_{RUN_IN,DEPLOYED}.stp` | stage 1/2 actuator sub-assembly, collapsed and deployed (Ø1.688 → Ø5.750), 23 bodies |
| `manifest_actuators.json` | machine-readable actuator BOM |
| `manual/ACTUATOR_MANUAL.md` | stage 1/2 actuator manual (SHEX-MAN-003 **Rev B**): design, sizing, manufacturing, arming/operation, **trigger/interlock (DCN-12)** |
| `../analysis/FIRST_STROKE_TRIGGER.md` | **trigger & EQ-interlock design memo (SHEX-EM-001 / DCN-12)**; numbers in `../analysis/trigger_design.py` |
| `../full_tool/step/SHEX-BP-UHEX-54_FULL_{RUN-IN,SET}.stp` | **complete tool Rev B** (plug + stage 1/2 actuators incl. SHEX-017) in run-in (47 bodies) and set (48 bodies); generated by `generate_full_tool.py` |
| `../full_tool/{stl,png}/`, `../full_tool/manifest_full_tool.json` | complete-tool meshes, previews, and BOM |

Regenerate everything with:

```
.venv\Scripts\python generate_release.py
.venv\Scripts\python export\drawings\generate_release_drawings.py
.venv\Scripts\python export\release\render_previews.py
```

## Design Change Notices

The `export/drawings/part_specs/*.md` shop sheets contained mutually
contradictory or physically impossible dimensions. The release geometry
resolves them as DCN-1..DCN-6. Each is also flagged on the affected
drawing sheet.

- **DCN-1 — Helix drive re-architected as a 2-start lead screw.**
  The spec put 0.080-deep helical grooves in a Ø1.552-ID insert riding a
  Ø1.550 mandrel body: zero wall. Resolution: the mandrel is necked to
  Ø1.270 over Z 10.4–23.0 (so the fixed SHEX-002 insert never sits over
  Ø1.550 body at any stroke position) with 2-start helical drive ribs at
  Z 19–23 (round form 0.115 W × 0.080 H, peak Ø1.429, lead 4.000).
  SHEX-002 ID changed 1.552 → Ø1.282 so the mating grooves have wall to
  live in (groove root Ø1.442).
- **DCN-2 — SHEX-011A tail sleeve.** Spec had OD 1.350 < ID 1.352
  (impossible). Resolution: ID 1.352 over the Ø1.350 tail, OD 1.550.
- **DCN-3 — Mandrel finished length 52.500.** The spec's Z 51–54 Ø1.550
  stub cannot coexist with the SHEX-012 Ø0.750 bore. Resolution: body to
  the joint shoulder at Z=51.0 plus a Ø1.500 × 1.5 pin stub.
- **DCN-4 — Plug overall length 57.0 in** with SHEX-012 Rev D 6.000 neck.
- **DCN-5 — SHEX-013 radial stack rebuilt.** Spec sleeve OD 1.680 could
  not enter the Ø1.562 body bore, and 0.070-deep grooves cut through
  every wall in the spec stack. Resolution: mandrel Ø1.350 tail extended
  through the sub zone (step moves Z 3.0 → 5.0); body OD 1.688 / ID 1.476
  with 2 internal gland grooves (0.045 deep) straddling the ports; sleeve
  OD 1.470 / ID 1.354 sliding inside the body over the seals.
- **DCN-6 — Top joint re-sequenced** so thread, seal and shoulder can all
  mate: mandrel shoulder at Z=51.0; pin Ø1.500 × 1.5 (1-1/2-12 UNF-2A
  thread 51–52, plain seal nose 52–52.5, Parker 2-216 face groove in the
  nose end face); SHEX-012 female: thread at mouth 0–1.0, seal bore
  Ø1.530 over 1.0–1.5.
- **DCN-7 — Settability: fishing neck downsized (Rev E).** The top joint was
  reshaped so a setting sleeve can pass over the neck and land on the upper
  slip carrier face at Z=51 (Ø1.375 pin, Rev E neck Ø1.450 body, GS profile
  retained for retrieval). Enables the SHEX-AK-20 adapter kit.
- **DCN-8 — Net set stroke re-budgeted 11.0 → 10.0 in** (+0.25 overtravel =
  10.25 demand) to fit a Baker E-4 No. 20 (10.777 in stroke) and #20-class CT
  tools (~10.5–11 in). Release stud calibrated to 45 klbf ±5%.
- **DCN-9 — Iris drive interference fix + module re-index.**
- **DCN-10 — Stent material.** SHEX-008/009 stage-1/2 stents re-specified from
  17-4 PH H900 to a **ductile expandable alloy** (annealed 316L or Ni alloy):
  a pressure/balloon-expandable mesh must plastically hinge ~2x; H900 is too
  brittle and would crack. (Stage 1/2 actuator package, SHEX-MAN-003.)
- **DCN-11 — Stage-2 prime mover.** Changed from a Belleville/swage wedge to a
  **second inflatable bladder**. A rigid expander starting <= stent ID 1.562
  cannot grow to back the Ø5.624 deployed stent in the 0.146-in annulus
  (geometrically impossible); the Belleville stack is retained only as a
  hold-open / anti-recoil preload. (SHEX-MAN-003.)
- **DCN-12 — First-stroke initiation & sequencing.** Replaced the passive
  hydrostatic-referenced burst-disk trigger (p1<p2 + time orifice), which has
  no position control and fires during run-in (proven, `trigger_design.py` §1),
  with **commanded initiation** (CT applied differential + ball seat, or e-line
  EFI gate) + **completion-gated sequencing** (each stent's bottom-out pressure
  shifts an arming sleeve that enables the next stage), with the **EQ pilot
  interlocked to close first**. Adds sub **SHEX-017** (+ 017A arming sleeve,
  017B reference piston); re-tasks SHEX-013/014C/015E/016A; defines fail-safe
  states. (SHEX-EM-001 / SHEX-MAN-003 Rev B.)

## Modelling notes / known limitations

- The run-in assembly represents the iris segments, petals and slips as
  nested collapsed arcs inside the Ø1.688 envelope. The source documents
  describe "stent-like crimping" of these rigid parts, which is not
  geometrically possible; the collapsed positions shown are the kinematic
  intent (parts stacked at minimum radius), not an elastic deformation.
- Stage-1/-2 stent sleeves (SHEX-008/-009) are exported in the run-in
  (laser-cut, un-expanded) state — that is the as-manufactured geometry.
  In the SET assembly they are shown at their expanded diameters with the
  cell pattern re-mapped to the expanded radius.
- The SET assembly includes a 5.5-in 17# casing section (ID 4.892) as a
  reference body named `REF-casing`. Delete or hide it for FEA meshing.
- STEP bounding boxes around the helical features (SHEX-002, SHEX-011,
  stent sleeves) read slightly oversize in some CAD packages because the
  B-spline control hulls extend past the true surface. Mesh-verified true
  extents: SHEX-002 is exactly L 4.000, OD 1.555, bore Ø1.282.
- Round-trip integrity verified for all 15 part files: 1 solid per file,
  0 orphan surfaces after re-import.

## Verified part volumes (re-imported from STEP)

| Part | Solids | Volume (in³) | Qty/plug |
|---|---|---|---|
| SHEX-001 iris segment | 1 | 5.359 | 16 |
| SHEX-002 helix guide | 1 | 2.336 | 1 |
| SHEX-003 MTM ring segment | 1 | 0.991 | 12 |
| SHEX-004 HNBR seal preform | 1 | 0.139 | 4 |
| SHEX-005 petal backup | 1 | 1.651 | 64 |
| SHEX-006 upper slip segment | 1 | 4.467 | 8 |
| SHEX-007 lower slip segment | 1 | 4.467 | 8 |
| SHEX-008 stage-1 stent (run-in) | 1 | 1.258 | 1 |
| SHEX-009 stage-2 stent (run-in) | 1 | 1.589 | 1 |
| SHEX-010 support sleeve | 1 | 2.112 | 1 |
| SHEX-011 inner mandrel | 1 | 89.658 | 1 |
| SHEX-011A mandrel tail sleeve | 1 | 1.354 | 1 |
| SHEX-012 fishing neck | 1 | 7.845 | 1 |
| SHEX-013 equalizing sub body | 1 | 1.010 | 1 |
| SHEX-013S sliding sleeve | 1 | 0.308 | 1 |

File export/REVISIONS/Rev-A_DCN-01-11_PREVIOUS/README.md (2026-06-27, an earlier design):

# Rev A — DCN-01..11 (PREVIOUS)

Complete tool: **44 bodies (run-in) / 45 bodies (set)** — regenerated here with the
DCN-12 sequence sub switched OFF.

Plug + setting kit + stage 1/2 bladder actuators (DCN-10 ductile stent, DCN-11
second bladder). The first-stroke **trigger/interlock is not present** at this
revision (it is added at Rev B / DCN-12).

## Contents
- `engineering/` — analysis scripts + data (no trigger memo).
- `design/` — `MANUAL.md`, `SETTING_TOOL_MANUAL.md`, `ACTUATOR_MANUAL_RevA_note.md`,
  `figures/`.
- `part-specs/`, `drawings/`, `step/parts` (no SHEX-017), `step/assemblies`
  (ACT-S12 subs, 20 bodies), `step/full-tool`, `stl/full-tool`, `previews/`.

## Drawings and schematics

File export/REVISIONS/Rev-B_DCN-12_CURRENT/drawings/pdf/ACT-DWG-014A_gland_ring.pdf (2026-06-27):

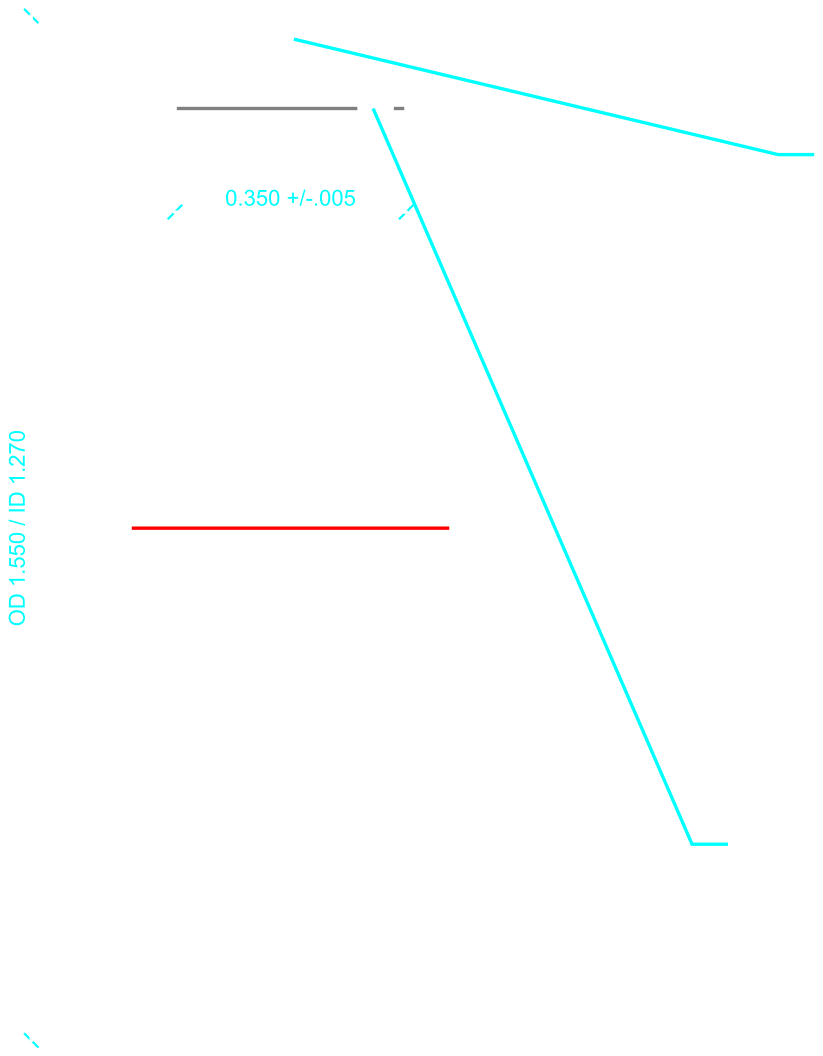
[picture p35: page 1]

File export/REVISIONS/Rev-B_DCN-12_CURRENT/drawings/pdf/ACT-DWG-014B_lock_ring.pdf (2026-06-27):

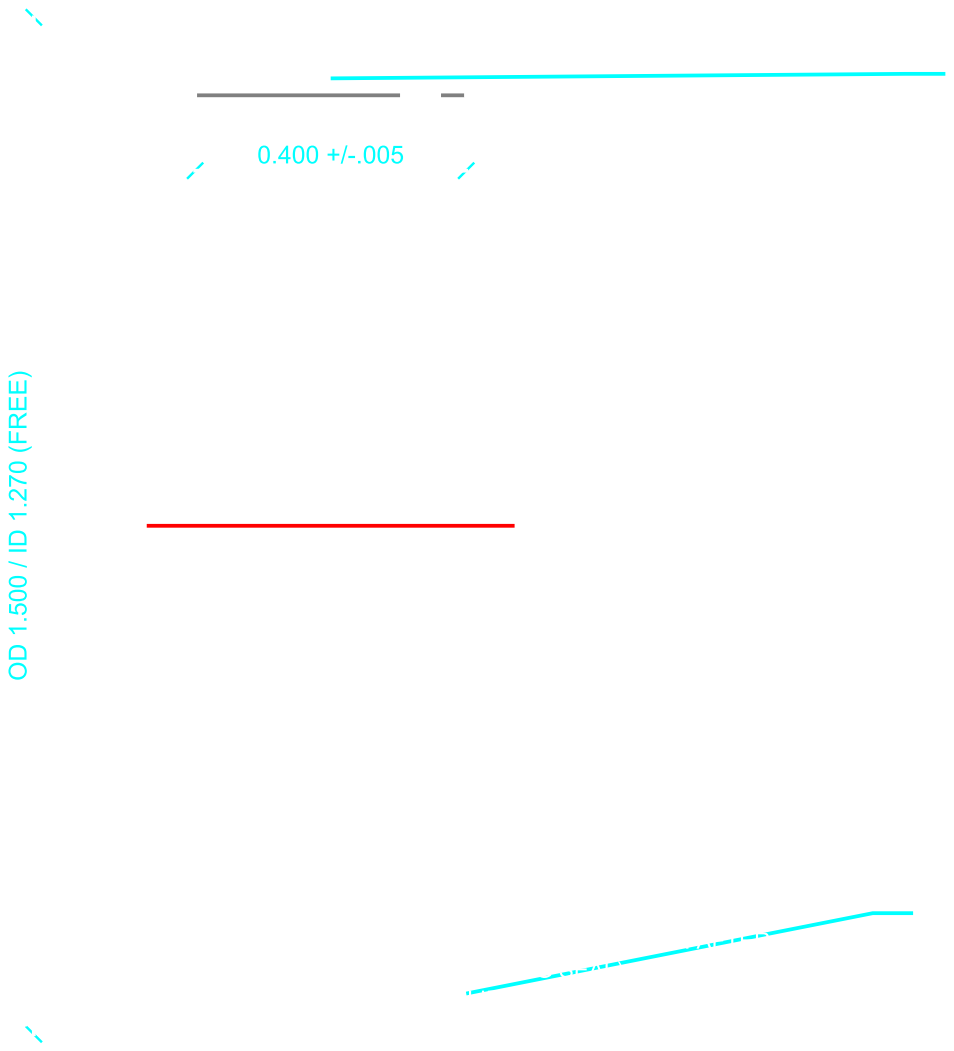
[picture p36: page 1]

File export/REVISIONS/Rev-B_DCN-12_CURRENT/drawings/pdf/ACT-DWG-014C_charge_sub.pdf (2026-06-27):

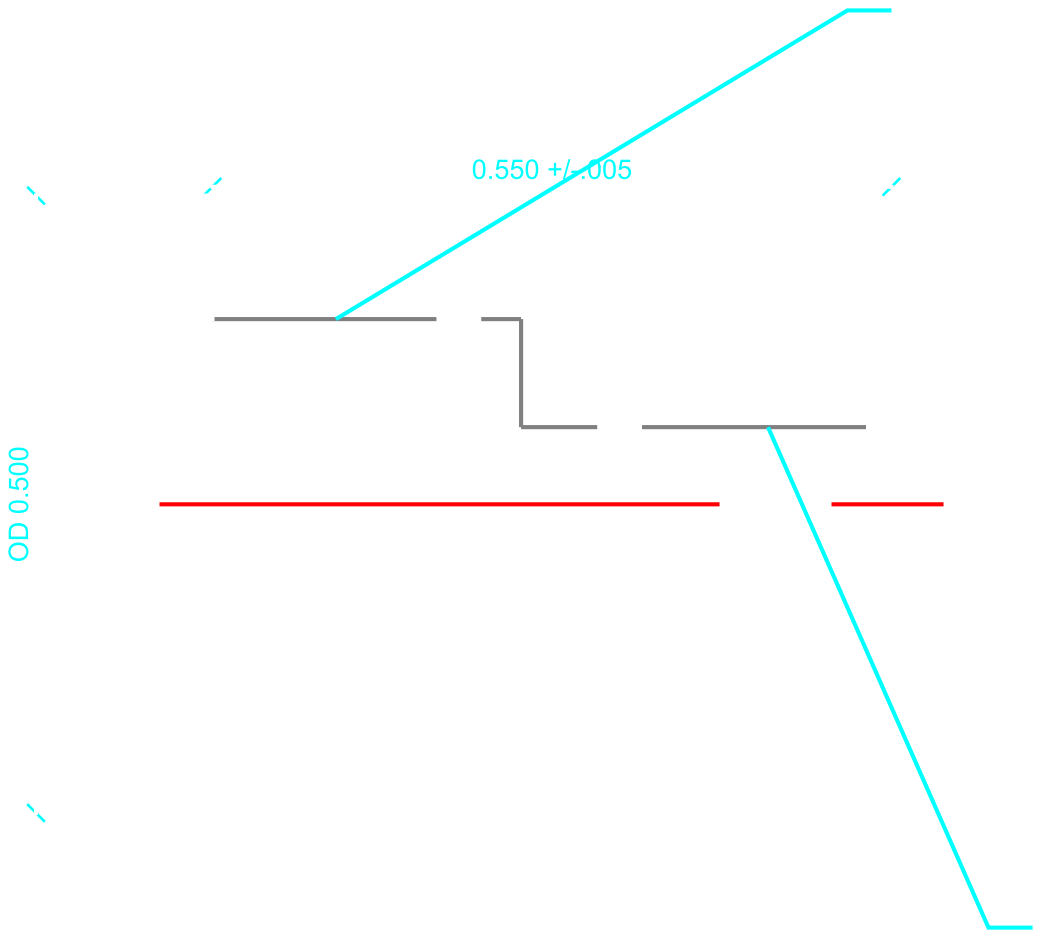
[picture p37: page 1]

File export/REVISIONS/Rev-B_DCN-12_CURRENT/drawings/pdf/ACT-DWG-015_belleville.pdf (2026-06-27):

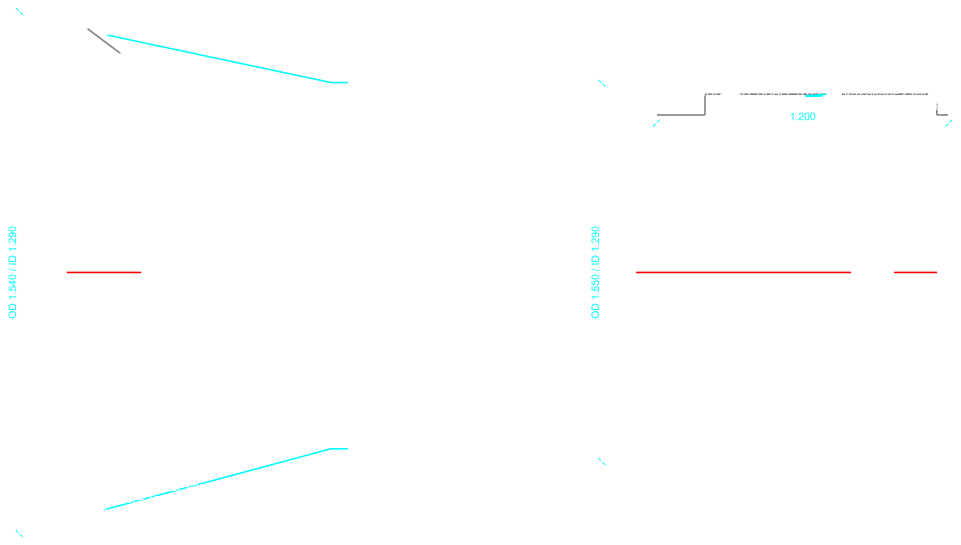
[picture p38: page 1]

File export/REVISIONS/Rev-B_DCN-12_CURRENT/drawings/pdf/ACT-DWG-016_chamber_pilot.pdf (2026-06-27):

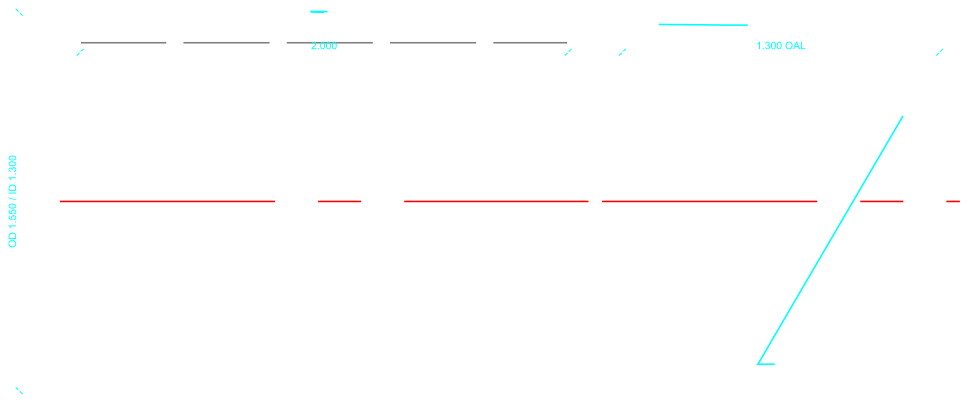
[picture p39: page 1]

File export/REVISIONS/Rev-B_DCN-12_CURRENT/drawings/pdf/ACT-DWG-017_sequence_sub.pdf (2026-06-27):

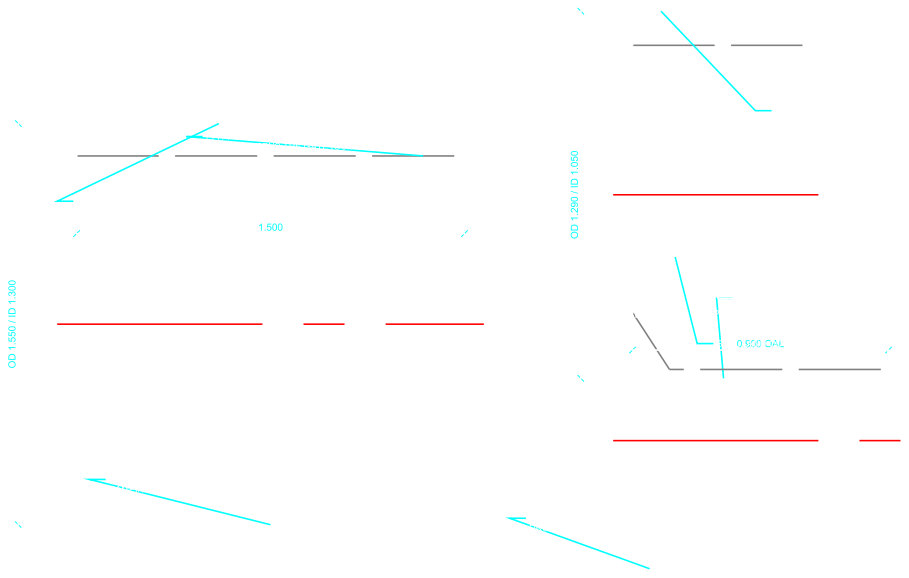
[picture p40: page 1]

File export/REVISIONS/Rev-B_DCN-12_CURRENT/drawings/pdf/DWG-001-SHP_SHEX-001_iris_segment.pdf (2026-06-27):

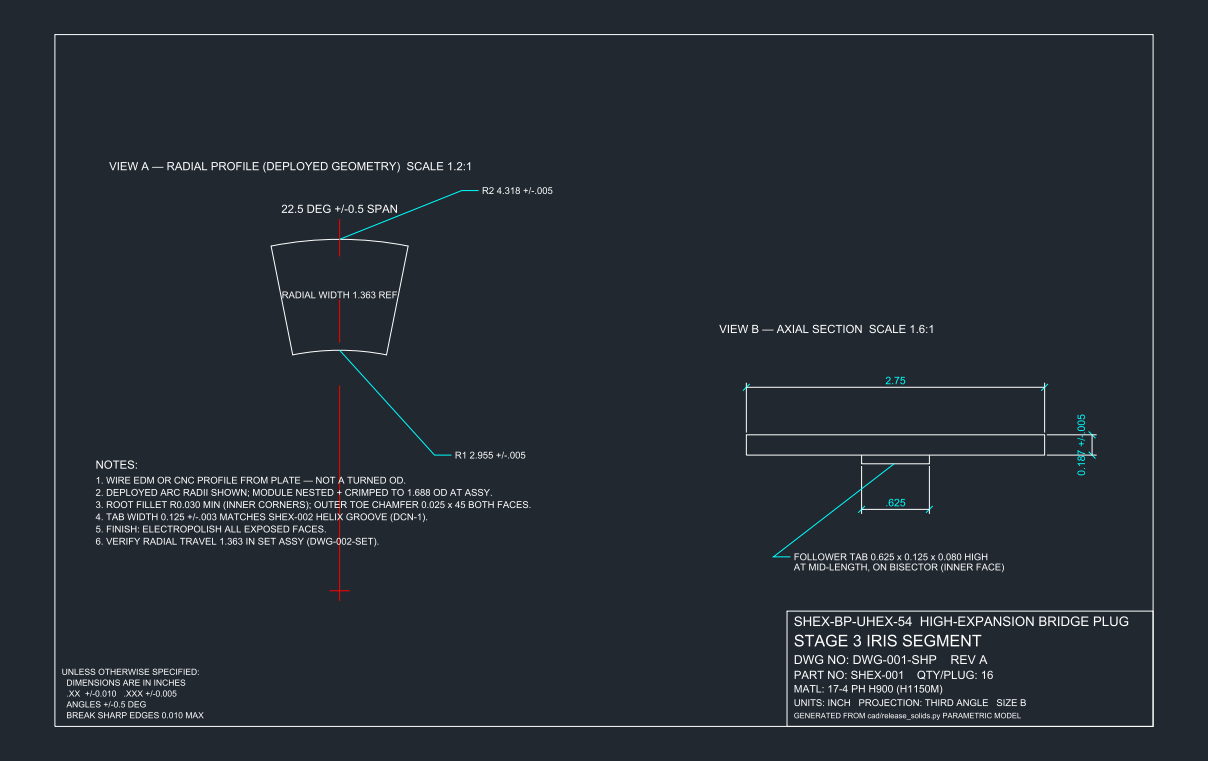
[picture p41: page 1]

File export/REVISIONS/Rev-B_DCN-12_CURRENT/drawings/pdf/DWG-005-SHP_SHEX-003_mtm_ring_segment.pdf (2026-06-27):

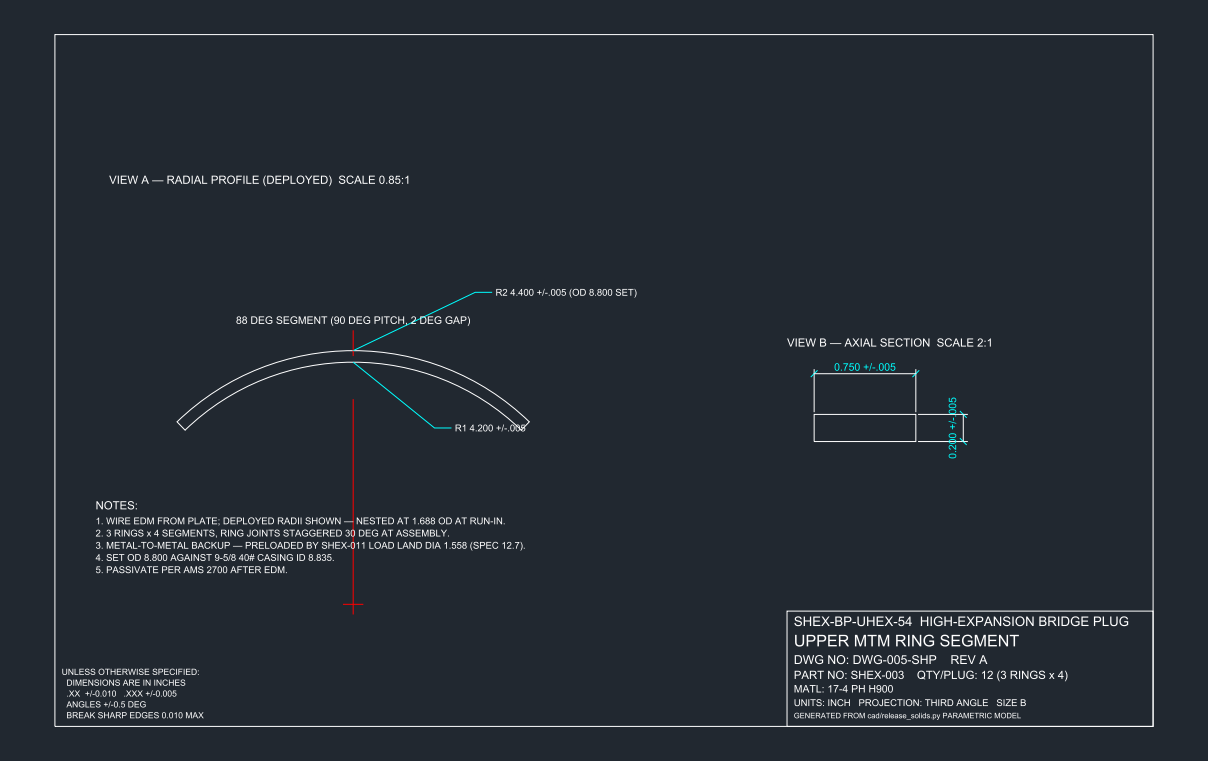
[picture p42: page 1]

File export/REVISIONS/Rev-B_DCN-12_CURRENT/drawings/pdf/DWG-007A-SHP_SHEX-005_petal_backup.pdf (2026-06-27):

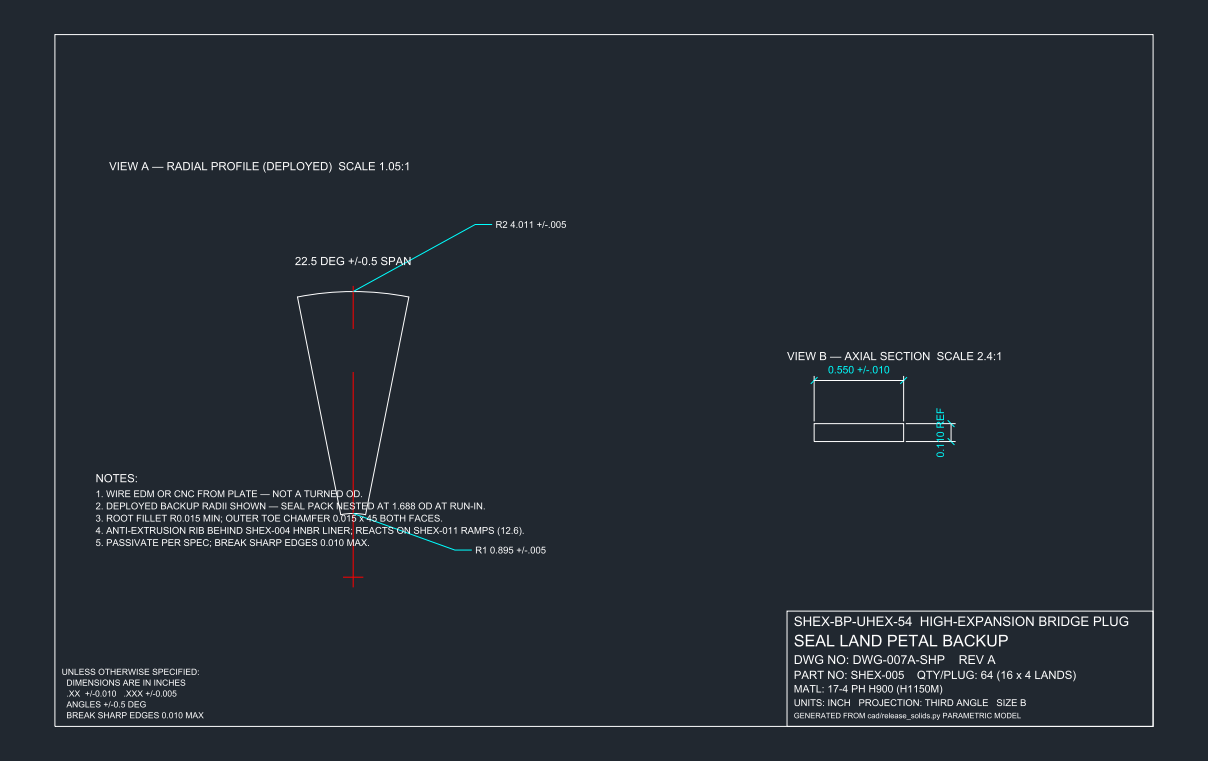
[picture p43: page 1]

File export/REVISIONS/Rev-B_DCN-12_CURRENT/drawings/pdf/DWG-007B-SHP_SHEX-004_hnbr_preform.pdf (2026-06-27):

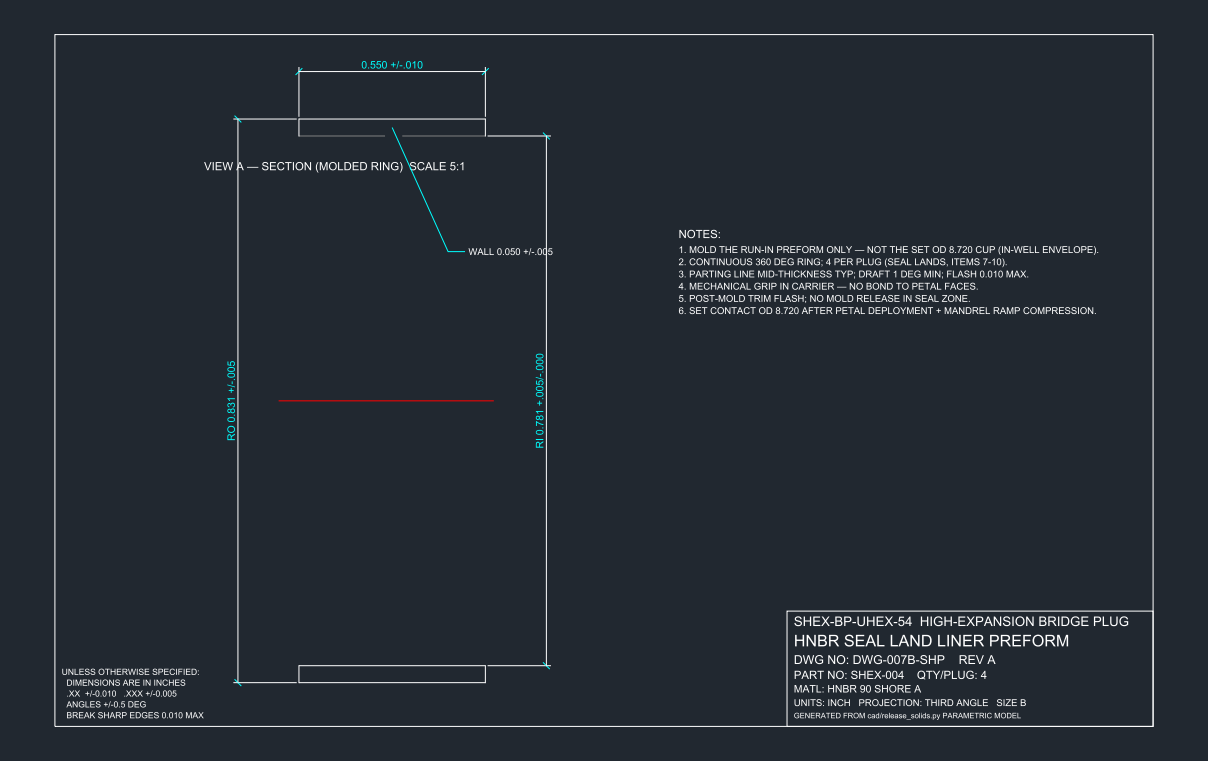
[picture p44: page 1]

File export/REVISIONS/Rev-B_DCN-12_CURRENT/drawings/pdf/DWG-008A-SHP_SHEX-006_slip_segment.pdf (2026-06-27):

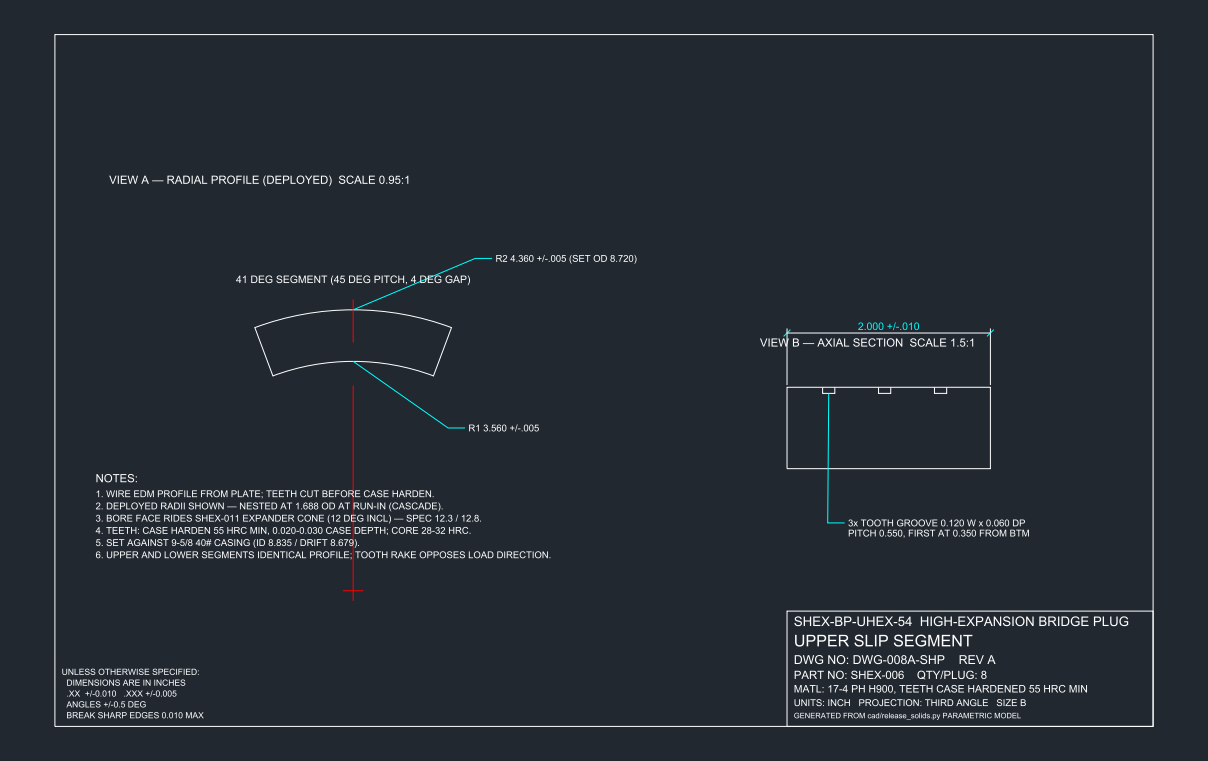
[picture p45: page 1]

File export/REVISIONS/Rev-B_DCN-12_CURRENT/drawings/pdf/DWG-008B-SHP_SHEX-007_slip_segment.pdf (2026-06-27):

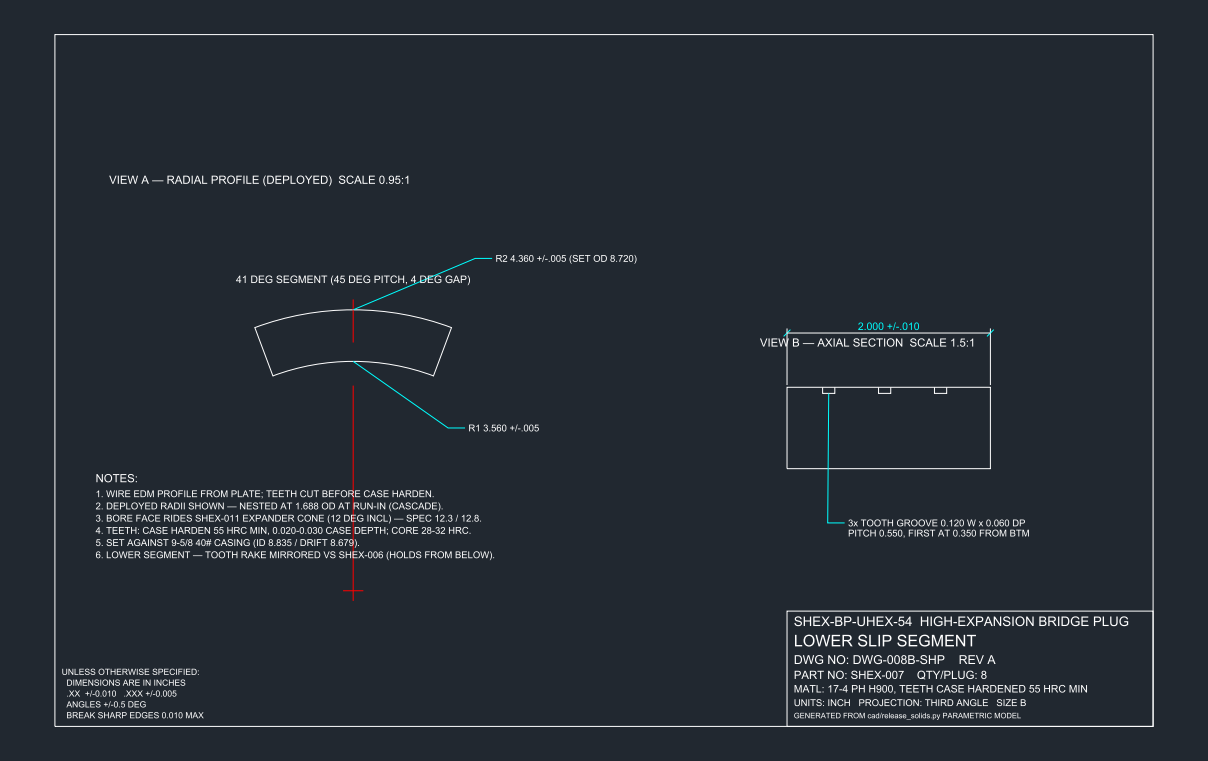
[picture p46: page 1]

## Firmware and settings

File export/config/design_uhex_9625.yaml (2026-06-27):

# SHEX-BP Ultra-High Expansion — 9-5/8" 40# Casing
# Run OD 1.688" | Set ID 8.679" drift | Max tool length 72"

tool:
  name: SHEX-BP-UHEX-9625
  run_od_in: 1.688
  set_casing_od_in: 9.625
  set_casing_weight_lbft: 40
  set_casing_nominal_id_in: 8.835
  set_casing_drift_id_in: 8.679
  max_tool_length_in: 72.0          # 6 feet
  expansion_ratio_diameter: 5.14    # drift_id / run_od
  max_differential_psi_target: 5000
  conveyance: ["wireline", "slickline", "coiled_tubing"]

# Multi-stage cascade expansion (nested stent modules)
# Single stent cannot achieve 5.14x — medical max ~2.5-3x per stage
expansion_cascade:
  stages: 3
  stage_1:
    collapsed_od_in: 1.688
    expanded_od_in: 3.375
    ratio: 2.00
    axial_length_in: 4.0
    mechanism: inner_stent_bladder
  stage_2:
    collapsed_od_in: 3.375
    expanded_od_in: 5.750
    ratio: 1.70
    axial_length_in: 5.0
    mechanism: middle_stent_wedge
  stage_3:
    collapsed_od_in: 5.750
    expanded_od_in: 8.650
    ratio: 1.50
    axial_length_in: 6.0
    mechanism: outer_stent_petal_iris
  total_expansion_axial_in: 15.0
  setting_stroke_in: 24.0           # long-stroke setting tool (Halliburton DPU-I-LS class)

# Tool length budget (72" max)
length_budget_in:
  fishing_neck_top_sub: 3.0
  upper_slip_assembly: 4.5
  equalizing_ports: 1.5
  mtm_ring_stack_upper: 3.0
  seal_stack: 36.0                  # primary pressure seal zone
  mtm_ring_stack_lower: 3.0
  expansion_cascade_module: 15.0
  lower_slip_assembly: 4.5
  bottom_sub: 2.0
  setting_piston_mandrel: 2.5
  total: 72.0

seal:
  deployed_od_in: 8.720
  element_length_in: 4.0
  element_count: 9                  # 36" total HNBR
  backup_per_element: mtm_petal
  petal_count_per_land: 16

slips:
  upper_and_lower: true
  segments_each: 8
  casing_contact_arc_in: 1.2

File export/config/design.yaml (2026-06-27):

# Stent-Inspired High-Expansion Retrievable Bridge Plug (SHEX-BP)
# Target: thru-tubing deployment, stent/catheter expansion mechanics

tool:
  name: SHEX-BP-169
  variant_primary_od_in: 1.688      # 1.69" run-in OD
  variant_alt_od_in: 2.125          # fallback for higher pressure rating
  set_casing_in: 4.5
  set_casing_id_in: 4.090           # 4.5", 11.6 lb/ft nominal ID
  max_differential_psi_target: 3000
  max_temperature_f: 300
  conveyance: ["wireline", "slickline", "coiled_tubing"]

# Stent geometry scaled from peripheral vascular stent (~6mm deployed)
# to oilfield bridge plug (~4.09" deployed ID)
stent:
  pattern: zigzag_sinusoidal        # Bx Velocity / Cypher class
  cells_around: 12
  ring_count: 8
  strut_width_in: 0.045
  strut_thickness_in: 0.035
  connector_style: sinusoidal
  collapsed_id_in: 1.450            # crimped on mandrel
  expanded_id_in: 4.050             # deployed against casing
  axial_length_in: 3.25
  material: "17-4 PH H900"
  manufacturing: "laser_cut_tube + heat_treat + electropolish"

expansion:
  mechanism: hybrid_mechanical_bladder
  # Catheter analog: inner mandrel + outer sheath during run-in
  # Balloon analog: internal elastomer bladder pressurized by setting stroke
  setting_stroke_in: 10.5
  setting_force_klbf: 25
  expansion_ratio: 2.79             # OD collapsed -> set diameter

seal:
  type: molded_hnbr_cup
  axial_length_in: 1.75
  backup_style: petal_metal         # Interwell HEX-inspired
  petal_count: 8

slips:
  style: segmented_wedge
  segment_count: 6
  set_after_seal_compression: true  # TTS sequencing

retrieval:
  method: pull_to_release
  fishing_neck: 1.375_ammt
